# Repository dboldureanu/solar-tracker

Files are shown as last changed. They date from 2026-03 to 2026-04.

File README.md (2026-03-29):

# Solar Tracker Project

A custom-built solar tracking system powered by an ESP32, designed to control multiple linear actuators with a user-friendly interface and safe power management.

---

## Overview

This project controls **three linear actuators** used to adjust the position of a solar panel system.
It features a **rotary encoder + LCD interface**, allowing manual control, monitoring, and future automation.

The system is designed with:
- Safe **power sequencing** (buck converter + relays)
- Modular **hardware architecture**
- Expandable **firmware (FSM-based design)**

---

## Features

- Real-time clock (RTC) display
- Rotary encoder navigation (pages + control mode)
- Safe actuator control via relay sequencing
- Buck converter pre-charge + main relay logic
- Microwave-style timing control (+30s / -30s)
- LCD interface (20x4 I2C)
- Potentiometer feedback for calibration
- Expandable for sensors (INA226 monitoring)

---

## System Architecture

The system is divided into several subsystems:

- **Control Unit** -> ESP32 (main logic)
- **User Interface** -> LCD + rotary encoder
- **Power System** -> 48V -> buck converter -> relays
- **Actuation** -> 3x linear actuators
- **Sensors** -> RTC + optional current/voltage monitors

---

## Documentation

Full project documentation is in the `docs/` folder:

| File | Topic |
|---|---|
| [01-overview.md](docs/01-overview.md) | System architecture and purpose |
| [02-hardware.md](docs/02-hardware.md) | Hardware components |
| [03-wiring.md](docs/03-wiring.md) | Wiring and pin mapping (single source of truth) |
| [04-power-architecture.md](docs/04-power-architecture.md) | Power design and sequencing |
| [05-firmware.md](docs/05-firmware.md) | Firmware architecture and FSM |
| [06-ui-behavior.md](docs/06-ui-behavior.md) | UI behavior and interaction |
| [pinout.md](docs/pinout.md) | Quick-reference pin table |

---

## Getting Started

### Requirements

- ESP32 DevKit board (ESP32-WROOM-32 / 32D, 38-pin)
- Arduino IDE
- USB cable (Type-C or Micro-B depending on board)

### Arduino IDE Setup

#### 1. Install ESP32 board support

1. **File** -> **Preferences**
2. In **"Additional Board Manager URLs"**, paste:
   ```
   https://raw.githubusercontent.com/espressif/arduino-esp32/gh-pages/package_esp32_index.json
   ```
   (If you already have other URLs, separate them with a comma)
3. Click **OK**
4. **Tools** -> **Board** -> **Boards Manager**
5. Search for **"esp32"**, install **"ESP32 by Espressif Systems"**

#### 2. Install required libraries

- **Tools** -> **Manage Libraries**, then search and install:
  - **hd44780** by Bill Perry (LCD driver)
- `Wire` is built-in, no installation needed

#### 3. Board settings

- **Tools** -> **Board** -> select **"ESP32 Dev Module"**
- **Tools** -> **Port** -> select the COM port your ESP32 is connected to
- All other settings can stay at defaults

### Building and uploading

1. Open `SolarTracker/SolarTracker.ino` in Arduino IDE
2. Click **Verify** (checkmark) to compile without uploading
3. Connect ESP32 via USB
4. Click **Upload** (arrow) to flash the firmware
5. **Tools** -> **Serial Monitor** at 115200 baud (optional, for debug output)

### Project directories

- `SolarTracker/` — current clean firmware (modular, multi-file)
- `SolarTracker/SolarTrackerCalibrationAndTesting.ino.bak` — original single-file firmware (reference only)

---

## Safety Notes

- Never connect **12V or higher directly to ESP32 VIN**
- Ensure **common ground** between all power sources
- Use proper **relay sequencing** (handled in firmware)
- USB + external power should be **isolated with a diode**

---

## Future Improvements

- Automatic sun tracking algorithm (clock-based scheduling)
- WiFi / remote control
- Data logging
- Closed-loop actuator positioning
- Safety limits and fault detection

---

## License

TBD

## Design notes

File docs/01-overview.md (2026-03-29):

# System Overview

This document describes the overall architecture and purpose of the Solar Tracker system, including its main components and how they interact.

---

## Purpose

The system is designed to control the position of **9 solar panels** (arranged in 3 rows of 3) using **three linear actuators** — one per row — for **azimuth tracking** (east-to-west sun following). Tilt is adjusted manually.

The installation is located in **Chisinau, Moldova** (latitude 47.0°N, longitude 28.8°E).

The primary goals are:
- Reliable actuator control
- Safe power management
- Simple and intuitive user interaction
- Clock-based automatic sun tracking

---

## High-Level Architecture

The system is composed of the following main subsystems:

```
        +---------------------+
        |     User Input      |
        |  (Rotary Encoder)   |
        +----------+----------+
                   |
                   v
        +---------------------+
        |      ESP32 MCU      |
        |   (Control Logic)   |
        +----+----+----+------+
             |    |    |
             |    |    |
 +-----------+    |    +-----------+
 |                |                |
 v                v                v
+---------+ +-----------+ +-------------+
|   LCD   | |    RTC    | |   Sensors   |
|  (I2C)  | |  DS3231   | |   INA226    |
+---------+ +-----------+ +-------------+
                  |
                  v
        +-------------------+
        |   Relay Control   |
        +---------+---------+
                  |
                  v
        +-------------------+
        |  Linear Actuators |
        |   (3x Motors)     |
        +-------------------+

                  ^
                  |
        +-------------------+
        |   Power System    |
        |  (Buck + Relays)  |
        +-------------------+
```

---

## Subsystems Description

### 1. Control Unit (ESP32)

The **ESP32 DevKitC** acts as the central controller:
- Handles user input (encoder)
- Drives relays
- Manages UI (LCD)
- Communicates with RTC and sensors via I2C
- Executes control logic using a **non-blocking FSM**

---

### 2. User Interface

**Components:**
- Rotary encoder (with push button)
- I2C LCD display (20x4 characters)

**Responsibilities:**
- Page navigation
- Enter/exit control mode
- Display system status (time, actuator info, timers)
- Provide feedback during actuator movement

---

### 3. Actuation System

- **9 solar panels** in 3 rows of 3 (each panel ~60 x 120 cm)
- 3 independent **linear actuators** (one per row, azimuth only)
- Each actuator: 450 mm stroke, 12V, 900N thrust, ~5 mm/s speed (~90s full travel)
- Each actuator controlled by **2 relays** (direction control)
- Only one direction active at a time
- Built-in 10 kOhm potentiometer for position feedback

**Behavior:**
- Controlled in timed pulses
- Direction selected via encoder rotation
- Duration adjustable dynamically (+/-30s steps)

**Tracking strategy:**
- Primary: clock-based positioning (calculate sun azimuth from time + Chisinau coordinates)
- Secondary: potentiometer feedback for closed-loop position verification
- Fallback: timed movement (actuator speed is ~5 mm/s, determined experimentally)

---

### 4. Power System

The actuators are powered through a controlled sequence:

```
48V Source
    |
    v
Buck Converter (48V -> 12V)
    |
    v
Pre-charge Relay
    |
    v
Main Relay
    |
    v
Actuator Relays
    |
    v
Linear Actuators
```

**Key concept:**
- The buck converter is **not always on**
- It is enabled only when movement is required
- Controlled via **two relays (PRE + MAIN)**

---

### 5. Sensors

**RTC (DS3231)**
- Keeps track of date and time
- Battery-backed
- Used for display and future automation

**INA226 (optional / planned)**
- Measures voltage, current, power
- Enables monitoring and diagnostics

**Potentiometers**
- Provide analog feedback
- Used for actuator calibration

---

## Software Architecture

The firmware is designed around:

### 1. State-based control (FSM)
Handles:
- Power sequencing
- Actuator movement lifecycle
- Safe transitions

### 2. Non-blocking execution
- Uses `millis()` instead of delays
- Allows UI + control to run simultaneously

### 3. Page-based UI
- 4 pages: Clock, Actuator A, Actuator B, Actuator C

---

## Typical Operation Flow

1. System boots -> displays clock page
2. User rotates encoder -> switches pages
3. User selects actuator page
4. User presses button -> enters control mode
5. User rotates encoder -> actuator starts moving
6. System:
   - Powers buck (PRE -> MAIN)
   - Activates actuator relay
   - Runs for defined duration
7. User can:
   - Increase time (+30s)
   - Decrease time (-30s)
   - Stop movement early
8. System safely powers down:
   - Actuator OFF -> MAIN OFF -> PRE OFF

---

## Design Principles

- **Safety first** -> controlled power sequencing
- **Non-blocking logic** -> responsive UI
- **Modularity** -> easy to extend
- **Clarity** -> explicit states and transitions

---

## Notes

- Only one actuator is controlled at a time
- Relays are **active LOW**
- USB + external power coexist with proper isolation
- Manual control is working; clock-based automatic tracking is the next step

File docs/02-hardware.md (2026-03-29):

# Hardware Components

This document describes all physical components used in the Solar Tracker system, including control boards, actuators, power elements, and interface devices.

---

## Control Unit

### ESP32 DevKitC v4

- Main microcontroller of the system
- Dual-core processor with WiFi/Bluetooth capability
- Operates at 3.3V logic level
- Provides:
  - GPIO control for relays
  - ADC inputs for potentiometers
  - I2C communication (RTC, LCD, sensors)
  - Encoder input handling

---

## User Interface

### I2C LCD Display

- **Model:** LCD2004, 20x4 character LCD, [AliExpress listing](https://aliexpress.ru/item/1005006831710761.html)
- Interface: I2C via PCF8574 backpack (auto-detected by `hd44780_I2Cexp` driver)
- I2C address: auto-detected (typically 0x27 or 0x3F)

| Parameter | Value |
|---|---|
| Resolution | 20x4 characters |
| Controller chip | SPLC780C / HD44780 compatible |
| Operating voltage | 3.3V |
| Power consumption | 40 mA |
| Display type | STN/FSTN |
| Backlight | Blue (white on blue) or Yellow-green |
| Display area | 70.1 x 20.76 mm |
| Module dimensions | 98 x 60 x 14 mm |
| Character size | 2.94 x 4.74 mm |
| Operating temperature| -20 to +70 C |

- Used for:
  - Displaying system status
  - Navigation feedback
  - Actuator control information

### Rotary Encoder (with push button)

- Model: **EC11** (Stlxy), [AliExpress listing](https://aliexpress.ru/item/10000056483250.html)
- Type: Incremental rotary encoder (A/B quadrature signals)
- 20 detent positions, 360-degree rotation
- Integrated momentary push button
- 5-pin (A, B, Button, GND, GND)
- Used for:
  - Page navigation
  - Entering/exiting control mode
  - Adjusting actuator movement duration

---

## Actuation System

### Linear Actuators (x3)

- Used to physically move/adjust the solar panel
- Each actuator supports:
  - Bidirectional movement
  - Controlled via polarity switching (relays)
  - Built-in potentiometer for position feedback
  - Built-in end-stop limit switches (both ends)

**Model:** XINHUANGDUO BHTGA-DW ([AliExpress listing](https://aliexpress.ru/item/1021789697.html))

| Parameter | Value |
|---|---|
| Stroke | 450 mm |
| Operating voltage | 12V DC |
| Max current | 2.5 A |
| Max push force (thrust) | 900 N |
| Max pull force | 750 N |
| Static load (forced) | 950 N |
| Max load | 1500 N |
| Self-locking force | 2300 N |
| Feedback potentiometer | Linear (1k / 5k / 10k options) |
| End-stop limit switches | Built-in (both ends) |
| Speed (approx) | ~5 mm/s (~90s full stroke) |
| Power | 20W |
| Motor type | Brushed, permanent magnet |
| Protection rating | IP65 (IEC-60529) |
| Operating temperature | -26 to +65 C |
| Operating humidity | 5-95% (non-condensing) |
| Duty cycle | 20% |
| Lifespan | 50,000 full cycles |
| Construction | Aluminum alloy tube/rods, zinc alloy housing, powder metal gears |

### Relay Modules

- Total relays used: **8** (6-channel module for actuators + 2-channel module for buck control)
- Brand: **Liludin**, optocoupler-isolated, low-level trigger
- [AliExpress listing](https://aliexpress.ru/item/1005004651717236.html)

| Parameter | Value |
|---|---|
| Trigger level | Active LOW (0-2V for 5V version) |
| Trigger current | 2 mA |
| Quiescent current | 4 mA (5V version) |
| Operating current | 65 mA (5V version) |
| Contact rating | 250V 10A AC / 30V 10A DC |
| Isolation | Optocoupler |
| Operating temperature| -45 to +85 C |
| Mounting | 3.1 mm bolt holes |

**Allocation:**

| Function | GPIO | Description |
|---|---|---|
| Actuator A | 13, 14 | Direction control |
| Actuator B | 16, 17 | Direction control |
| Actuator C | 18, 19 | Direction control |
| Buck Main | 23 | Enables main power  |
| Buck Pre-charge  | 25 | Soft-start |

**Notes:**
- Each actuator uses **2 relays** (forward/reverse)
- Only one direction must be active at a time
- All relays default to **OFF (HIGH)**
- Each relay has NO (normally open), NC (normally closed), and COM terminals

---

## Power System

### Primary Source

- **48V battery bank**: 4x 12V 200Ah lead-acid gel batteries in series
- Nominal voltage: 48V (range ~42-56V depending on charge state)

### ESP32 Power: HV DC-DC Buck (48V -> 5V)

Powers the ESP32 and logic-level components (always on).

- **Chip:** XL7035 (replaces XL7015 / LM2596HV)
- **Brand:** eletechsup, [AliExpress listing](https://aliexpress.ru/item/32824319280.html)

| Parameter | Value |
|---|---|
| Input voltage | 10-80V DC |
| Output voltage | 5V DC (fixed) |
| Max output current | 1A |
| Switching frequency | 150 kHz |
| Max efficiency | 85% |
| Quiescent current | ~2.5 mA |
| Operating temperature | -40 to +85 C |
| Dimensions | 59 x 30 x 16 mm |

**Protections:** reverse polarity input, overvoltage (TVS), overcurrent, thermal shutdown, short circuit.

### Actuator Power: Buck Converter (48V -> 12V)

Powers the linear actuators. **Not always on** — enabled only when movement is required, controlled via two relays with safe power sequencing.

- **Type:** 200W synchronous buck module (non-isolated), [AliExpress listing](https://aliexpress.ru/item/1005010087482983.html)
- Output voltage adjustable via potentiometer (default 12V)

| Parameter | Value |
|---|---|
| Input voltage | 8-55V DC (abs max 60V) |
| Output voltage | 1-36V DC adjustable (set to 12V)|
| Output current | 10A continuous, 15A peak |
| Output power | 100W natural cooling, 200W with enhanced cooling |
| Switching frequency | 180 kHz |
| Max efficiency | 94% |
| Operating temperature | -10 to +85 C |
| Dimensions | 70 x 38 x 31 mm (aluminum case) |
| Connection | Screw terminals (no soldering) |

**Protections:** overcurrent (>15A), reverse polarity input.

### Buck Control Relays

Two relays are used to safely control the actuator buck converter:

1. **Pre-charge relay** (GPIO 25)
   - Allows gradual energizing
   - Reduces inrush current

2. **Main relay** (GPIO 23)
   - Supplies full power after stabilization

### USB Power (Development)

- ESP32 can also be powered via USB
- Used for programming and serial debugging

**Isolation:**
- USB 5V line is **diode-isolated** (1N4007)
- Prevents backfeeding into the laptop

---

## Sensors

### DS3231 RTC Module

- **Chip:** DS3231SN with AT24C32 EEPROM (32Kbit)
- **Brand:** Liludin, [AliExpress listing](https://aliexpress.ru/item/1005001875764383.html)
- Module: DS3231 mini module (3.3V/5V compatible)
- Battery: LIR2032 rechargeable (keeps clock running when main power is off)
- Communicates via I2C (RTC address 0x68, EEPROM address 0x57 — adjustable via A0/A1/A2)
- I2C max speed: 400 kHz at 5V

| Parameter | Value |
|---|---|
| Operating voltage | 3.3-5.5V |
| Clock accuracy | +/-2 ppm (0-40 C range, ~1 min/year) |
| Temperature sensor | Built-in, +/-3 C accuracy |
| EEPROM | AT24C32, 32Kbit |
| Alarms | 2 configurable |
| Square wave output | Programmable |
| Calendar valid until | Year 2100 (with leap year compensation) |
| Dimensions | 38 x 22 x 14 mm |

### INA226 Current/Voltage Sensors (optional)

- **Chip:** INA226, **Brand:** diymore, [AliExpress listing](https://aliexpress.ru/item/1005006460678073.html)
- I2C current/voltage/power monitor with shunt resistor

| Parameter | Value |
|---|---|
| Bus voltage range | 0-36V DC |
| Current range | -20A to +20A (bidirectional) |
| Supply voltage | 2.7-5.5V |
| Resolution | 16-bit (1.25 mA current, 1.25 mV voltage) |
| Accuracy | 1% |
| Power consumption | ~330 uA (typ), <1 mA |
| Interface | I2C (up to 16 addresses via A0/A1 solder jumpers) |
| Alert output | Programmable alarm pin |
| Operating temperature  | -40 to +125 C |
| Dimensions | 20 x 27 mm |

- Used for monitoring actuator current draw and system diagnostics
- Connected to ESP32 INA ALERT pin (GPIO 27) for alarm notifications

### Potentiometers (x3)

- **Built into the linear actuators** (10 kOhm linear)
- Connected to ESP32 ADC1 pins (GPIO 34, 35, 36)
- Provide analog position feedback for each actuator
- Used for calibration and position estimation

**Signal conditioning circuit (per channel):**

```
Actuator pot (0-5V) ──[ 1kΩ series ]──┬── ESP32 ADC pin (0-3.3V)
                                       |
                                  [ 100nF ]
                                       |
                                      GND
                                       |
                                  [ 10kΩ pull-down ]
                                       |
                                      GND
```

- **1 kOhm series resistor**: limits current into ADC, protects ESP32
- **100 nF capacitor to GND**: low-pass RC filter (RC = ~100 us), smooths voltage spikes and mechanical noise
- **10 kOhm pull-down**: prevents floating voltage at mid-stroke
- Note: a voltage divider may be needed to scale 5V pot output to 3.3V ADC range

---

## Passive Components

### Diodes

- Used for power isolation
- Current: **1N4007**
  - Prevents reverse current into USB
  - Installed inline on USB 5V (VCC)

> For better efficiency, Schottky diodes (e.g., 1N5819) are recommended in future revisions.

---

## Connectivity

### I2C Bus

Shared by: LCD, RTC, INA226 sensors

### GPIO

Used for: relay control, encoder signals, button input

---

## Important Notes

- All grounds (**GND**) must be common across: ESP32, power system, sensors
- Relays are **active LOW**
- External power must be properly regulated before reaching the ESP32

---

## Future Hardware Improvements

- Replace mechanical relays with MOSFET-based drivers
- Add end-stop sensors for actuators
- Add hardware protection (fuses, TVS diodes)
- Improve power isolation (ideal diode or power mux)

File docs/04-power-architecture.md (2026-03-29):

# Power Architecture

This document describes how power is generated, controlled, and safely delivered to the system components.

The design ensures:
- Safe startup and shutdown
- Controlled high-current switching
- Protection of both hardware and USB-connected devices

---

## Overview

The system uses a **48V battery bank** (4x 12V 200Ah lead-acid gel in series) which is stepped down by two separate converters.

```
48V Battery Bank (4x 12V 200Ah gel, series)
    |
    +---> HV Buck XL7035 (48V -> 5V, always on)
    |         |
    |         v
    |     ESP32 + sensors + LCD (logic power)
    |
    +---> Buck Converter (48V -> 12V, relay-controlled)
              |
              v
          Pre-charge Relay (GPIO 25)
              |
              v
          Main Relay (GPIO 23)
              |
              v
          Actuator Relays (GPIO 13-19)
              |
              v
          Linear Actuators
```

---

## Power Domains

### 1. High Power Domain

- **48V battery bank** (4x 12V 200Ah lead-acid gel, series)
- Nominal 48V (range ~42-56V depending on charge state)
- Feeds both buck converters

### 2. Intermediate Power (12V)

- Output of the relay-controlled buck converter
- Supplies linear actuators only
- Not always on — enabled only during movement

### 3. Logic Power (5V / 3.3V)

- **HV DC-DC buck module** (XL7035, 10-80V -> 5V, 1A max)
- Always on when battery is connected
- Powers ESP32, sensors, LCD
- ESP32 internal regulator provides 3.3V from 5V

Additional source:
- USB (development only, diode-isolated)

---

## Buck Converter Control

The buck converter is **not permanently active**.
It is enabled only when actuator movement is required.

### Control Relays

| Relay | Function |
|---|---|
| Pre-charge | Soft-start / limits inrush |
| Main | Full power enable |

---

## Power Sequencing (Critical)

To prevent electrical stress and ensure safe operation, the following sequence is enforced:

### Startup Sequence

1. **Pre-charge relay ON**
   - Allows gradual capacitor charging
2. Wait (~400 ms)
3. **Main relay ON**
   - Full power applied
4. Wait (~150 ms)
5. **Actuator relay ON**
   - Movement begins

### Shutdown Sequence

1. **Actuator relay OFF**
2. Wait (~100 ms)
3. **Main relay OFF**
4. Wait (~150 ms)
5. **Pre-charge relay OFF**

### Why this matters

- Prevents **inrush current spikes**
- Protects relays and buck converter
- Avoids voltage dips affecting ESP32
- Ensures longer hardware lifespan

---

## USB + External Power Coexistence

The ESP32 may be powered simultaneously by:
- USB (from laptop)
- External regulated 5V

### Problem

Without protection:
- External power can **backfeed into USB**
- Risk of damaging the laptop

### Solution: Diode Isolation

A diode is added in the USB 5V line:

```
Laptop USB 5V ──|>|──> ESP32 5V
```

- Allows power from USB -> ESP32
- Blocks power from ESP32 -> USB

### Implementation

- Diode used: **1N4007**
- Orientation:
  - Anode -> USB side
  - Cathode (stripe) -> ESP32 side

### Voltage Drop

- Typical drop: ~0.7V
- Result: ESP32 receives ~4.3V from USB
- Still within acceptable operating range

### Future Improvement

- Replace with **Schottky diode** (e.g., 1N5819)
  - Lower drop (~0.2-0.3V)
  - More efficient

---

## Grounding

All system parts must share a **common ground**:
- ESP32
- Buck converter
- Relay modules
- Sensors
- External power source

> This is essential for stable operation and correct signal reference.

---

## Safety Considerations

### DO

- Use proper voltage regulation (48V -> 12V -> 5V)
- Verify polarity before powering
- Ensure solid connections for high-current paths

### DO NOT

- Connect 12V directly to ESP32 VIN/5V
- Operate relays without proper sequencing
- Use floating grounds
- Connect USB to a system with unknown ground potential

---

## Risk Areas

- High current during actuator startup
- Relay contact wear over time
- Voltage spikes from inductive loads (actuator motors)

---

## Recommended Protections (Future)

- Flyback diodes on relay coils
- TVS diodes for surge protection
- Fuses on power lines
- Current limiting on actuator lines

---

## Notes

- Power system is designed for **intermittent operation**, not continuous load
- Buck converter should not remain powered unnecessarily
- Firmware enforces all sequencing logic

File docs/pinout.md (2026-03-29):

# ESP32 Pin Mapping (Quick Reference)

## GPIO Assignments

| GPIO | Function  | Connected To | Notes |
|---|---|---|---|
| 13 | Relay | Actuator A - Direction 1  | Active LOW |
| 14 | Relay | Actuator A - Direction 2  | Active LOW |
| 16 | Relay | Actuator B - Direction 1  | Active LOW |
| 17 | Relay | Actuator B - Direction 2  | Active LOW |
| 18 | Relay | Actuator C - Direction 1  | Active LOW |
| 19 | Relay | Actuator C - Direction 2  | Active LOW |
| 23 | Relay | Buck MAIN relay | Active LOW |
| 25 | Relay | Buck PRE-charge relay | Active LOW |
| 32 | Input | Encoder A | INPUT_PULLUP |
| 33 | Input | Encoder B | INPUT_PULLUP |
| 26 | Input | Encoder Button | INPUT_PULLUP |
| 34 | ADC | Potentiometer A | Input-only |
| 35 | ADC | Potentiometer B | Input-only |
| 36 | ADC | Potentiometer C | Input-only |
| 27 | Input | INA ALERT | INPUT_PULLUP |
| 21 | I2C SDA | LCD, RTC, INA226 | Shared bus |
| 22 | I2C SCL | LCD, RTC, INA226 | Shared bus |

---

## Power Pins

| Pin | Function | Notes |
|---|---|---|
| VIN / 5V | Power input | From USB or external 5V |
| 3V3 | Regulated output | Internal ESP32 regulator |
| GND | Ground | Must be common everywhere |

---

## Special Notes

### Input-only pins
- GPIO **34, 35, 36** cannot be used as outputs
- Used for ADC (potentiometer readings)

### Active LOW relays

All relay pins:

| Signal | Meaning |
|---|---|
| LOW | Relay ON |
| HIGH | Relay OFF |

### I2C Bus

- SDA -> GPIO 21
- SCL -> GPIO 22

Devices on the bus:
- LCD display
- RTC (DS3231)
- INA226 sensors

### Avoided Pins

Pins intentionally not used:
- GPIO 0, 2, 15 -> boot-strapping pins
- GPIO 6-11 -> used by internal flash memory

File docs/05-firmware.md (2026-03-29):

# Firmware Architecture

This document describes the structure, logic, and design principles of the firmware running on the ESP32.

The firmware is responsible for:
- User interaction (encoder + LCD)
- Actuator control
- Power sequencing
- Timing and state management

---

## High-Level Structure

The firmware follows a **non-blocking, state-driven architecture**:

```
loop()
├── pollEncoder()
├── tickMoveFSM()
├── drawUI()
└── periodicTasks()
```

---

## Core Concepts

### 1. Non-blocking Execution

- Uses `millis()` instead of `delay()`
- Allows:
  - Responsive UI
  - Concurrent operations
  - Smooth timing control

### 2. Finite State Machine (FSM)

The actuator movement and power control are implemented using a **state machine**.

---

## Move FSM

### States

```
Idle
 ├─ PreOn
 ├─ MainOn
 ├─ ActOn
 ├─ ActOffPause
 ├─ MainOff
 └─ PreOff
```

### State Descriptions

| State | Description |
|---|---|
| Idle | No movement |
| PreOn | Pre-charge relay ON |
| MainOn | Main relay ON |
| ActOn | Actuator running |
| ActOffPause | Short delay after stop |
| MainOff | Main relay OFF |
| PreOff | Pre-charge OFF |

### Transition Flow

```
Idle → PreOn → MainOn → ActOn → ActOffPause → MainOff → PreOff → Idle
```

### Timing Constants

| Constant | Value | Purpose |
|---|---|---|
| `PRECHARGE_MS` | 400 ms | Soft-start |
| `MAIN_STAB_MS` | 150 ms | Stabilization |
| `PULSE_MS` | 30000 ms | Base movement time |
| `POST_ACT_PAUSE_MS`| 100 ms  | Safe stop |
| `BUCK_SPINDOWN_MS` | 150 ms | Power-down |

---

## Input Handling

### Rotary Encoder

- Quadrature decoding (A/B signals)
- Accumulates steps
- Converts into actions:
  - Page navigation
  - Actuator control

### Sensitivity Control

| Mode | Constant | Value | Purpose |
|---|---|---|---|
| Navigation | `NAV_TICKS_PER_ACTION` | 4 | Prevent oversensitivity |
| Control | `CTRL_TICKS_PER_PULSE` | 2 | Avoid accidental triggers |

### Button Handling

- Detects rising edge (press)
- Used for:
  - Entering control mode
  - Exiting control mode

---

## UI System

### Page-Based Design

| Page | Description |
|---|---|
| 0 | Clock |
| 1 | Actuator A  |
| 2 | Actuator B  |
| 3 | Actuator C  |

### Rendering Strategy

- Only redraw when needed
- Clock updates every second
- Actuator pages update dynamically

---

## Control Mode Logic

### Entry

- Press encoder on actuator page

### Behavior

- Encoder rotation triggers movement
- Direction:
  - CW -> one direction (dir2)
  - CCW -> opposite direction (dir1)

---

## Microwave-Style Timing

### Key Idea

While an actuator is running, encoder rotation adjusts the remaining time:
- **CW** (clockwise) always **adds +30 seconds** (regardless of which direction started the move)
- **CCW** (counter-clockwise) always **subtracts -30 seconds**

### Constants

| Constant | Value | Purpose |
|---|---|---|
| `PULSE_MS` | 30000 ms | Initial movement time  |
| `MOVE_INCREMENT_MS`| 30000 ms | Time added/removed |
| `MAX_MOVE_MS` | 60000 ms | Maximum run time cap |

### Behavior

1. First rotation -> starts movement (30s). CW starts dir2, CCW starts dir1.
2. While running, time adjustment is always:
   - CW: extend time (+30s, capped at 60s total from start)
   - CCW: reduce time (-30s)
3. If time reaches 0 -> actuator stops immediately, FSM begins shutdown
4. Note: CW/CCW for time adjustment is independent of which direction started the move

### Runtime Adjustment

While actuator is running:
- Encoder input modifies `move.nextAt`
- Remaining time recalculated dynamically
- Display updates continuously

---

## Early Stop Logic

If user reduces time to 0:
1. Actuator stops immediately
2. FSM continues shutdown sequence safely (ActOffPause -> MainOff -> PreOff -> Idle)

---

## Relay Control Logic

- All relays are **active LOW**
- Default state = OFF (HIGH)

### Actuator Control

| dir1 | dir2 | Result |
|---|---|---|
| LOW  | HIGH | Direction 1 |
| HIGH | LOW  | Direction 2 |
| HIGH | HIGH | Stop |

> Both LOW simultaneously must never occur (short circuit risk).

---

## ADC Handling

- Uses ESP32 ADC1 (pins 34, 35, 36)
- Reads potentiometers for actuator feedback
- 12-bit resolution (0-4095)
- 11 dB attenuation (~0-3.3V range)
- Applies multi-sample averaging (12 samples) for stability

---

## Periodic Tasks

| Task | Interval | Condition |
|---|---|---|
| Clock refresh | 1 second | On clock page |
| Potentiometer update  | ~200 ms  | On actuator page, not in control mode |

---

## Design Principles

- **Responsiveness** -> no blocking delays
- **Safety** -> enforced power sequencing
- **Predictability** -> explicit FSM states
- **Extensibility** -> easy to add features

---

## Future Improvements

- Event-driven architecture
- Task scheduling (RTOS)
- Persistent settings (EEPROM / NVS)
- Automated sun-tracking control algorithm

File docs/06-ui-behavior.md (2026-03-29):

# UI Behavior

This document describes how the user interacts with the system via the **rotary encoder and LCD**, including navigation, control modes, and on-screen feedback.

---

## Navigation Model

The UI is based on a **page system**, controlled by the rotary encoder.

### Pages

| Page Index | Name | Description |
|---|---|---|
| 0 | Clock | Displays date/time |
| 1 | Actuator A | Control page |
| 2 | Actuator B | Control page |
| 3 | Actuator C | Control page |

---

## Page Navigation

### Rotation (Normal Mode)

- Rotate encoder:
  - Clockwise -> next page
  - Counter-clockwise -> previous page

### Sensitivity

- Navigation requires multiple encoder ticks
- Controlled by `NAV_TICKS_PER_ACTION` (currently 4)
- Prevents accidental page switching

---

## Button Behavior

| Page | Button Action |
|---|---|
| Clock | No action |
| Actuator pages | Enter / Exit control mode |

---

## Control Mode

### Entering Control Mode

1. Navigate to an actuator page
2. Press encoder button

-> System enters **control mode**

### Exiting Control Mode

- Press encoder button again
- Returns to normal navigation mode
- If a move is in progress, the FSM continues its shutdown safely

---

## Control Mode Behavior

While in control mode:

### Encoder Rotation

| Direction | Action |
|---|---|
| Clockwise | Move actuator (dir2) |
| Counter-clockwise | Move actuator (dir1) |

---

## Microwave-Style Timing

The system uses a **cumulative timing model**, similar to a microwave.

### Behavior

- First rotation:
  - Starts actuator movement
  - Sets initial time = **30 seconds**
- Additional rotations (while running):
  - CW always adds **+30 seconds** (capped at 60s total from start)
  - CCW always subtracts **-30 seconds**
  - Note: this is independent of which direction started the move

### Examples

| Action | Result |
|---|---|
| Rotate CW once | Start 30s |
| Rotate CW again  | 60s total (max cap) |
| Rotate CCW once  | Back to 30s |
| Reduce to 0 | Movement stops |

---

## Stop Behavior

- If remaining time reaches **0**:
  - Actuator stops immediately
  - Power-down sequence begins (ActOffPause -> MainOff -> PreOff -> Idle)

---

## Display Layouts

### 1. Clock Page

```
Date & Time
YYYY-MM-DD
HH:MM:SS
Rotate: pages | Btn: -
```

- Updates every second
- Button has no effect

### 2. Actuator Page (Normal Mode)

```
Actuator A
POT: 2048  1.65V
Rotate: next/prev
Btn: Control mode
```

- Shows actuator name
- Potentiometer value (raw ADC + voltage)

### 3. Actuator Page (Control Mode - Idle)

```
Actuator A
POT: 2048  1.65V
CONTROL: rotate =>
Dir: CCW<-  ->CW
```

- Waiting for user input
- No movement active

### 4. Actuator Page (Running)

```
Actuator A
POT: 2048  1.65V
CONTROL: rotate =>
Remain: 00:25
```

- Displays remaining time as MM:SS
- Updates continuously

### 5. Time Adjustment Feedback

When adjusting time while running:

- Adding time:
  ```
  Remain: 01:00 (+30s)
  ```
- Reducing time:
  ```
  Remain: 00:30 (-30s)
  ```

---

## Real-Time Updates

| Element | Update Rate |
|---|---|
| Clock | 1 second |
| Potentiometer | ~200 ms |
| Remaining time | Continuous  |

---

## Interaction Summary

### Normal Mode

- Rotate -> change page
- Button -> enter control (only on actuator pages)

### Control Mode

- Rotate -> control actuator (direction + time)
- Button -> exit control mode

---

## Important Behavior Rules

- Only one actuator can be controlled at a time
- Control mode disables page navigation
- Movement continues even if UI updates
- FSM handles safe power transitions independently

---

## UX Notes

- Encoder sensitivity intentionally reduced to avoid accidental movements
- Visual feedback always matches system state

---

## Possible UI Improvements

- Add icons or arrows for direction
- Display actuator position as percentage
- Add warnings (overcurrent, limits)
- Add confirmation before movement
- Add menu/settings page

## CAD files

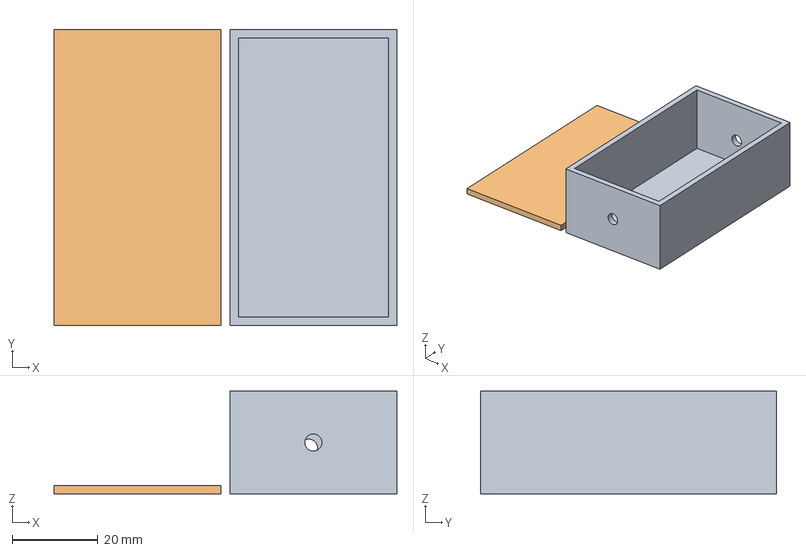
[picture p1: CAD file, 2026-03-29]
3d/Capac48to5V.3mf
80.0 x 69.0 x 24.0 mm
Cutie48to5V.stl
Capac48to5V.stl

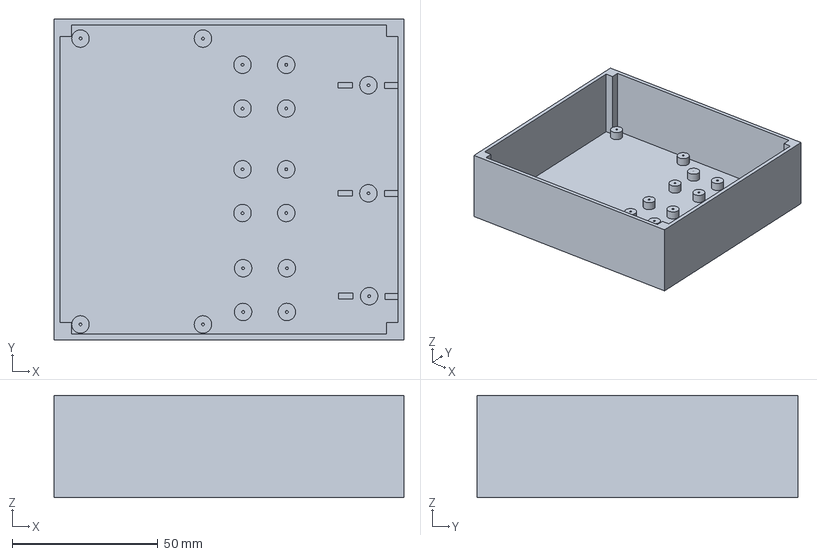
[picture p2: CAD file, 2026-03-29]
3d/RelaysCaseBase.3mf
120.0 x 110.0 x 35.0 mm

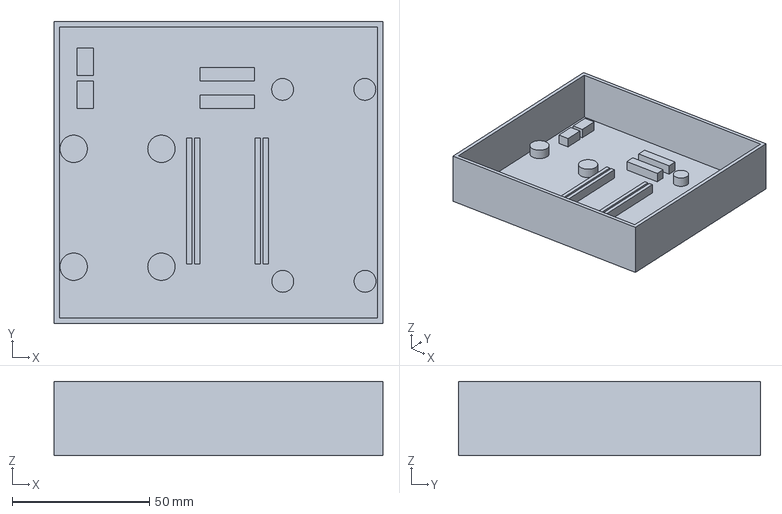
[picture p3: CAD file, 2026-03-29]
3d/Esp32Base.3mf
120.0 x 110.0 x 27.0 mm

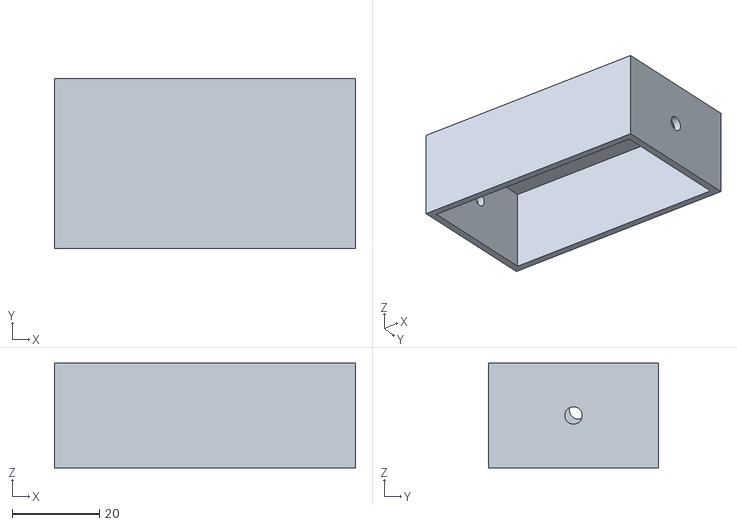
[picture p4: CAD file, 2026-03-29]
3d/Cutie48to5V.stl
69.0 x 39.0 x 24.0

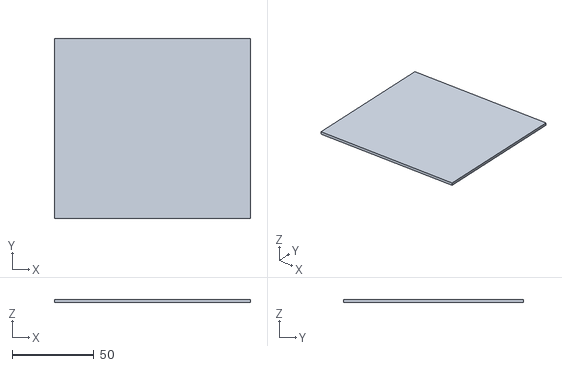
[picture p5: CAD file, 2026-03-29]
3d/CapacSolarTracker.stl
120.0 x 110.0 x 2.00

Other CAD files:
3d/Capac48to5V.stl
3d/Esp32Base.stl
3d/RelaysCaseBase.stl

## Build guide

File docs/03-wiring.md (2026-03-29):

# Wiring & Pin Mapping

This document defines all electrical connections between the ESP32 and the system components.
It is the **single source of truth** for pin assignments and wiring.

---

## ESP32 Pin Mapping

### I2C Bus

| Function | GPIO | Notes |
|---|---|---|
| SDA | 21 | Shared bus |
| SCL | 22 | Shared bus |

Connected devices:
- LCD (I2C)
- RTC (DS3231)
- INA226 sensors

---

### Actuator Relays

Each actuator is controlled by **2 relays** (direction control).

| Actuator | Direction | GPIO |
|---|---|---|
| A | dir1 | 13 |
| A | dir2 | 14 |
| B | dir1 | 16 |
| B | dir2 | 17 |
| C | dir1 | 18 |
| C | dir2 | 19 |

> Only one direction relay must be ON at a time.

---

### Buck Converter Control

| Function | GPIO | Description |
|---|---|---|
| Pre-charge relay | 25 | Enables soft-start |
| Main relay | 23 | Enables full power |

---

### Rotary Encoder

| Signal | GPIO | Notes |
|---|---|---|
| Encoder A | 32 | INPUT_PULLUP |
| Encoder B | 33 | INPUT_PULLUP |
| Button | 26 | INPUT_PULLUP |

---

### Potentiometers (ADC)

| Potentiometer | GPIO | ADC Channel |
|---|---|---|
| Actuator A | 34 | ADC1 |
| Actuator B | 35 | ADC1 |
| Actuator C | 36 | ADC1 |

> These are **input-only pins** (no digital output).

---

### Other Signals

| Function  | GPIO | Notes |
|---|---|---|
| INA ALERT | 27 | INPUT_PULLUP |

---

## Wiring Overview

### I2C Connections

All I2C devices share the same lines:

```
ESP32 GPIO21 (SDA) ─────┬── LCD
                         ├── RTC (DS3231)
                         └── INA226 modules

ESP32 GPIO22 (SCL) ─────┬── LCD
                         ├── RTC
                         └── INA226 modules
```

> Pull-up resistors are typically included on modules.

---

### Relay Wiring (Logic Side)

- Relay modules connect directly to ESP32 GPIOs
- Logic is **active LOW**:

| Signal | State | Meaning |
|---|---|---|
| LOW | ON | Relay activated |
| HIGH | OFF | Relay inactive  |

---

### Actuator Control Logic

Each actuator uses two relays:

```
dir1 = LOW,  dir2 = HIGH  ->  move one direction
dir1 = HIGH, dir2 = LOW   ->  move opposite direction
dir1 = HIGH, dir2 = HIGH  ->  STOP
```

> Never set both LOW simultaneously (short circuit risk).

---

### Buck Relay Wiring

```
ESP32 GPIO25  ->  Pre-charge relay
ESP32 GPIO23  ->  Main relay
```

Sequence:
1. PRE ON
2. MAIN ON
3. Actuator ON
4. Actuator OFF
5. MAIN OFF
6. PRE OFF

---

## Power Connections

### ESP32 Power

- Powered via:
  - USB (development)
  - OR external 5V (via VIN/5V pin)

### External Power System

```
48V Source
    |
    v
Buck Converter (48V -> 12V)
    |
    v
Relays (PRE + MAIN)
    |
    v
Actuators
```

### USB Power Isolation

USB 5V line modified with diode:

```
USB 5V ──|>|──> ESP32 5V
```

Prevents backfeeding into laptop.

---

## Critical Rules

### 1. Common Ground

All components MUST share GND:
- ESP32
- Buck converter
- Relays
- Sensors

### 2. Voltage Limits

- ESP32 GPIO: **3.3V only**
- VIN/5V pin: **5V only**
- NEVER connect 12V directly to ESP32

### 3. Relay Safety

- Default state must be OFF (HIGH)
- Avoid switching directions instantly
- Ensure proper sequencing

### 4. Encoder Stability

- Use INPUT_PULLUP
- Keep wires short
- Avoid noise near relay lines

---

## Debug Tips

- If LCD not detected -> check I2C address (use I2C scanner sketch)
- If relays inverted -> logic is active LOW, check wiring
- If encoder unstable -> check grounding and debounce
- If ADC noisy -> average readings in software (firmware uses 12-sample average)

---

## Notes

- Pin assignments are chosen to:
  - Avoid boot-strapping pins (GPIO 0, 2, 15)
  - Avoid flash memory pins (GPIO 6-11)
  - Use ADC1 channels (safe when WiFi is active)
  - Keep I2C on default pins (21, 22)

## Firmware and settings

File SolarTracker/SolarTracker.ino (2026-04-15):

#include <Wire.h>
#include <hd44780.h>
#include <hd44780ioClass/hd44780_I2Cexp.h>

#include "config.h"
#include "hardware.h"
#include "fsm.h"
#include "autotrack.h"
#include "ui.h"

// Global objects
hd44780_I2Cexp lcd;
Encoder encoder;
MoveFSM fsm;
AutoTrack autotrack;
UI ui;

void setup() {
  Serial.begin(115200);

  // Long settle delay at the very top of setup(). Wide-input switching
  // converters (XL7035 / LM2596HV clones) have slow soft-start and poor
  // transient response at cold boot; giving the 5 V rail a full second
  // to stabilize before we start drawing current avoids brown-out loops
  // and marginal I2C init.
  delay(1000);

  // GPIO inputs first — no current draw, harmless at any rail state.
  encoder.init();
  pinMode(INA_ALERT_PIN, INPUT_PULLUP);

  Wire.begin(I2C_SDA, I2C_SCL);
  // Explicitly pin the I2C clock to 100 kHz. Default varies by ESP32 core
  // version; at 400 kHz the rising edges on a ~20 cm shared bus with only
  // the hobby modules' weak internal pull-ups are marginal, which causes
  // occasional character corruption on the LCD. 100 kHz gives each edge
  // 4x more time to settle.
  Wire.setClock(100000);
  Wire.setTimeOut(50);

  // Let the LCD's internal HD44780 power-on reset finish before we start
  // talking to it (datasheet spec ~40 ms; we give it 200 for margin).
  delay(200);

  // LCD init with one retry — hd44780 cold-boot occasionally fails on the
  // first attempt after a marginal power rail and succeeds the second.
  int lcdStatus = lcd.begin(LCD_COLS, LCD_ROWS);
  if (lcdStatus) {
    Serial.print(F("LCD init failed: ")); Serial.println(-lcdStatus);
    delay(500);
    lcdStatus = lcd.begin(LCD_COLS, LCD_ROWS);
    if (lcdStatus) {
      Serial.print(F("LCD init retry failed: ")); Serial.println(-lcdStatus);
    } else {
      Serial.println(F("LCD init recovered on retry."));
    }
  }
  lcd.backlight();

  // Relay init AFTER LCD, matching the legacy firmware order. Keeping this
  // late means the 8 relay GPIOs stay in high-Z (relay modules pull them
  // high via their onboard resistors) until after we've successfully
  // talked to the LCD — fewer simultaneous current draws on the 5 V rail
  // during the critical I2C init window.
  initRelays();

  initAdc();
  Settings::load();

  if (RTC::isPresent()) {
    // Only seed the RTC if it looks uninitialized (dead coin cell / first boot).
    // Otherwise the set-time menu would be clobbered on every reboot.
    RTC::DateTime dt;
    if (!RTC::read(dt) || dt.year < 2024) {
      RTC::setFromCompileTime();
      Serial.println(F("RTC uninitialized; seeded from compile time."));
    } else {
      Serial.println(F("RTC OK; keeping current time."));
    }
  } else {
    Serial.println(F("RTC not found (skip set)."));
  }

  ui.init(lcd);
  ui.setAutoTrack(&autotrack);
  ui.drawCurrentPage(lcd);
}

void loop() {
  ui.handleInput(encoder, fsm, lcd);
  fsm.tick(lcd);
  autotrack.tick(fsm, ui.isUserBusy(), lcd);
  ui.refresh(fsm, lcd);
}

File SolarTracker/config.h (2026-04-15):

#pragma once

// ===== Relay Pins (active LOW) =====
// Each actuator has two direction relays, named by the tracking direction
// they drive the panels toward: east = morning/low-pot, west = evening/high-pot.
// Actuator C is wired with swapped polarity relative to A/B; the swap is
// expressed here so the rest of the code can stay direction-semantic.
struct ActuatorPins {
  int east;
  int west;
};

constexpr ActuatorPins ACTUATOR_PINS[] = {
  {13, 14},  // Actuator A
  {16, 17},  // Actuator B
  {19, 18},  // Actuator C (swapped in software to match wiring)
};
constexpr int ACTUATOR_COUNT = 3;

// Potentiometer calibration: raw ADC values at physical end stops.
// Measured 2026-04-13 with panels driven manually to each extreme.
struct PotCalibration {
  int east_raw;  // extreme east (morning)
  int west_raw;  // extreme west (evening)
};

constexpr PotCalibration POT_CAL[] = {
  {430, 3140},  // A
  {429, 3200},  // B
  {400, 3190},  // C
};

// ===== Monthly tracking window =====
// For each month: the tracking time window and the pot setpoints at its
// endpoints. Between start and end, the target pot is linearly interpolated.
// Outside the window, auto-tracking is idle.
struct MonthConfig {
  uint8_t  start_h;
  uint8_t  start_m;
  uint16_t start_raw;   // target pot at start-of-window (east-ish)
  uint8_t  end_h;
  uint8_t  end_m;
  uint16_t end_raw;     // target pot at end-of-window (west-ish)
};

constexpr uint8_t MONTH_COUNT = 12;

// Encoder pulse -> raw ADC delta when editing a pot setpoint.
constexpr int POT_EDIT_STEP = 10;

// ===== System (global auto-tracking) config =====
// Stored separately from per-month config in NVS.
struct SystemConfig {
  bool    auto_enabled;   // master on/off for auto-tracking
  uint8_t tick_min;       // evaluation interval, minutes (1..180)
};

// Tick interval bounds.
constexpr uint8_t TICK_MIN_MIN = 1;
constexpr uint8_t TICK_MIN_MAX = 180;

// ===== Auto-tracking tuning =====
// Dead-band around the target pot reading; |target - actual| <= this means
// "aligned, don't move". Units: raw 12-bit ADC counts.
constexpr int AUTO_DEADBAND_RAW = 20;

// Stall detection: if the pot hasn't moved by this many raw counts within
// AUTO_STALL_WINDOW_MS, abort the current actuator's move.
constexpr int           AUTO_STALL_DELTA_RAW = 10;
constexpr unsigned long AUTO_STALL_WINDOW_MS = 5000;

// Max consecutive FSM pulses per actuator per auto-track pass. Each pulse
// is PULSE_MS long (30s), so 3 pulses covers a full stroke (~90s).
constexpr uint8_t AUTO_MAX_PULSES = 3;

// All relay GPIO pins (actuators + buck), for bulk init.
constexpr int RELAY_PINS[] = {13, 14, 16, 17, 18, 19, 23, 25};
constexpr int RELAY_COUNT  = sizeof(RELAY_PINS) / sizeof(RELAY_PINS[0]);

// Buck converter control relays
constexpr int BUCK_MAIN_PIN = 23;
constexpr int BUCK_PRE_PIN  = 25;

// ===== Encoder Pins =====
constexpr int ENC_A   = 32;
constexpr int ENC_B   = 33;
constexpr int ENC_BTN = 26;  // LOW when pressed (INPUT_PULLUP)

// ===== Potentiometer ADC Pins (ESP32 ADC1) =====
constexpr int POT_PINS[] = {34, 35, 36};  // A, B, C

// ===== I2C =====
constexpr int I2C_SDA = 21;
constexpr int I2C_SCL = 22;

// ===== INA226 Alert (optional, not used yet) =====
constexpr int INA_ALERT_PIN = 27;

// ===== LCD =====
constexpr int LCD_COLS = 20;
constexpr int LCD_ROWS = 4;

// ===== Encoder Sensitivity =====
// Navigation mode: ticks required to change page
constexpr int NAV_TICKS_PER_ACTION = 4;
// Control mode: ticks required to trigger actuator
constexpr int CTRL_TICKS_PER_PULSE = 2;

// ===== Actuator Timing =====
// Initial movement duration when first triggered
constexpr unsigned long PULSE_MS = 30000UL;          // 30 seconds
// Time added/removed per encoder twist while running
constexpr unsigned long MOVE_INCREMENT_MS = 30000UL;  // +/- 30 seconds
// Maximum total run time
constexpr unsigned long MAX_MOVE_MS = 60000UL;        // 60 seconds

// ===== Buck Power Sequencing Timing =====
constexpr unsigned long PRECHARGE_MS      = 400;   // PRE relay -> MAIN relay
constexpr unsigned long MAIN_STAB_MS      = 150;   // MAIN relay -> actuator ON
constexpr unsigned long POST_ACT_PAUSE_MS = 100;   // actuator OFF -> MAIN relay OFF
constexpr unsigned long BUCK_SPINDOWN_MS  = 150;   // MAIN OFF -> PRE OFF

// ===== Periodic Update Intervals =====
constexpr unsigned long CLOCK_REFRESH_MS = 1000;   // clock page refresh
constexpr unsigned long POT_REFRESH_MS   = 200;    // potentiometer readout refresh

// ===== ADC =====
// 16 samples * ~1250us per sample ~= 20 ms, which covers one full 50 Hz
// mains cycle. This averages out hum and PWM aliasing that back-to-back
// samples would miss.
constexpr int           ADC_SAMPLES              = 16;
constexpr unsigned long ADC_INTERSAMPLE_US       = 1250;

// Median-of-N reads on top of readAdcAvg, for the few decision points
// where the occasional spike (e.g. relay click) would cause a bad move.
constexpr int ADC_STABLE_SAMPLES = 5;  // must be odd

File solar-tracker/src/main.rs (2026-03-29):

use esp_idf_svc::hal::delay::FreeRtos;
use esp_idf_svc::hal::gpio::PinDriver;
use esp_idf_svc::hal::peripherals::Peripherals;
use log::info;

fn main() {
    // Initialize ESP-IDF system (logger, event loop, etc.)
    esp_idf_svc::sys::link_patches();
    esp_idf_svc::log::EspLogger::initialize_default();

    info!("Solar Tracker - Phase 1: Blink & Serial");
    info!("ESP32 Rust toolchain is working!");

    let peripherals = Peripherals::take().unwrap();

    // Onboard LED is typically on GPIO 2 for ESP32 DevKit boards
    let mut led = PinDriver::output(peripherals.pins.gpio2).unwrap();

    let mut counter: u32 = 0;
    loop {
        led.set_high().unwrap();
        info!("LED ON  (cycle {})", counter);
        FreeRtos::delay_ms(500);

        led.set_low().unwrap();
        info!("LED OFF (cycle {})", counter);
        FreeRtos::delay_ms(500);

        counter += 1;
    }
}

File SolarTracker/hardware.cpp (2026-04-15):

#include "hardware.h"
#include <Preferences.h>

// =====================================================================
// Relay helpers
// =====================================================================

void initRelays() {
  for (int i = 0; i < RELAY_COUNT; i++) {
    pinMode(RELAY_PINS[i], OUTPUT);
    digitalWrite(RELAY_PINS[i], HIGH);  // OFF (active LOW)
  }
}

void allRelaysOff() {
  for (int i = 0; i < RELAY_COUNT; i++) {
    digitalWrite(RELAY_PINS[i], HIGH);
  }
}

void actuatorOff(uint8_t index) {
  digitalWrite(ACTUATOR_PINS[index].east, HIGH);
  digitalWrite(ACTUATOR_PINS[index].west, HIGH);
}

// =====================================================================
// ADC helpers
// =====================================================================

void initAdc() {
  analogReadResolution(12);  // 0..4095
  for (int i = 0; i < ACTUATOR_COUNT; i++) {
    pinMode(POT_PINS[i], INPUT);
    analogSetPinAttenuation(POT_PINS[i], ADC_11db);  // ~0..3.3V
  }
}

int readAdcAvg(int pin, int samples) {
  long acc = 0;
  for (int i = 0; i < samples; i++) {
    acc += analogRead(pin);
    // Spread samples across a full 50 Hz mains cycle (~20 ms for 16 samples)
    // so hum/PWM aliasing averages out instead of clustering.
    if (i + 1 < samples) delayMicroseconds(ADC_INTERSAMPLE_US);
  }
  return static_cast<int>(acc / samples);
}

int readAdcStable(int pin) {
  // Take ADC_STABLE_SAMPLES independent averages, return the median. One
  // spike (e.g. a relay flick) lands in a single sample and gets discarded.
  int buf[ADC_STABLE_SAMPLES];
  for (int i = 0; i < ADC_STABLE_SAMPLES; i++) {
    buf[i] = readAdcAvg(pin);
  }
  // Insertion sort — tiny N, branch-predictable.
  for (int i = 1; i < ADC_STABLE_SAMPLES; i++) {
    int v = buf[i], j = i - 1;
    while (j >= 0 && buf[j] > v) { buf[j + 1] = buf[j]; j--; }
    buf[j + 1] = v;
  }
  return buf[ADC_STABLE_SAMPLES / 2];
}

float adcToVolts(int raw) {
  return raw * (3.3f / 4095.0f);
}

// =====================================================================
// Encoder
// =====================================================================

void Encoder::init() {
  pinMode(ENC_A,   INPUT_PULLUP);
  pinMode(ENC_B,   INPUT_PULLUP);
  pinMode(ENC_BTN, INPUT_PULLUP);
  prev_ab_ = readAB();
}

uint8_t Encoder::readAB() {
  uint8_t a = digitalRead(ENC_A);
  uint8_t b = digitalRead(ENC_B);
  return (a << 1) | b;
}

int8_t Encoder::decodeStep(uint8_t nibble) {
  // Quadrature gray-code lookup.
  // nibble = (prev_AB << 2) | curr_AB
  switch (nibble) {
    case 0b0001: case 0b0111: case 0b1110: case 0b1000: return +1;
    case 0b0010: case 0b1011: case 0b1101: case 0b0100: return -1;
    default: return 0;
  }
}

void Encoder::poll() {
  // Poll at most once per millisecond to avoid noise.
  uint32_t now = millis();
  if (now - last_poll_ms_ < 1) return;
  last_poll_ms_ = now;

  // Rotation
  uint8_t curr = readAB();
  uint8_t nibble = ((prev_ab_ & 0x03) << 2) | (curr & 0x03);
  steps_ += decodeStep(nibble);
  prev_ab_ = curr;

  // Button (edge detection: idle HIGH, pressed LOW)
  bool pressed = (digitalRead(ENC_BTN) == LOW);
  if (pressed && !button_last_) {
    button_pressed_ = true;
  }
  button_last_ = pressed;
}

int Encoder::consumeSteps() {
  int s = steps_;
  steps_ = 0;
  return s;
}

bool Encoder::consumeButtonPress() {
  bool p = button_pressed_;
  button_pressed_ = false;
  return p;
}

// =====================================================================
// RTC (DS3231 via I2C)
// =====================================================================

namespace RTC {

static constexpr uint8_t ADDR = 0x68;

static uint8_t dec2bcd(uint8_t v) { return ((v / 10) << 4) | (v % 10); }
static uint8_t bcd2dec(uint8_t v) { return (v >> 4) * 10 + (v & 0x0F); }

bool isPresent() {
  Wire.beginTransmission(ADDR);
  return Wire.endTransmission() == 0;
}
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

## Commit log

2026-03-29 Initial commit: ESP32 solar tracker project
    - Modular Arduino C++ firmware (SolarTracker/): config, hardware, FSM, UI
    - Original single-file firmware kept as .bak reference
    - Comprehensive documentation (docs/): hardware specs, wiring, power architecture, firmware, UI
    - 3D print files for enclosures
    - Rust ESP32 project skeleton (solar-tracker/): future port
    [Capac48to5V.3mf, Capac48to5V.stl, CapacSolarTracker.stl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]
2026-04-14 Add clock-set and monthly-config menus; semantic east/west pins
    - Rename ActuatorPins dir1/dir2 to east/west; swap array C to compensate
    for its inverted physical wiring (expressed once, in the pin table).
    - Add POT_CAL[] with end-stop ADC readings measured on 2026-04-13.
    - New SetClock page: view current RTC time; button enters edit mode
    (Year -> Month -> Day -> Hour -> Minute -> Second) with encoder
    adjustment, day clamped by days-in-month (leap-year aware), final
    press commits to DS3231.
    - Gate RTC-from-compile-time seed: only runs when year < 2024 or read
    fails, so menu-set values survive reboots.
    - New Config page: per-month tracking window (Start/End time + pot
    setpoint) st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
    [SolarTracker.ino, config.h, hardware.cpp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]
2026-04-15 Phase 2: closed-loop auto-tracking + ADC noise reduction
    AutoTrack controller
    - New autotrack.{h,cpp}: state machine (Off/Outside/Idle/Active) that
    drives each array toward an interpolated target pot reading based
    on the per-month config and RTC time. Walks A -> B -> C sequentially
    (respects the single-active-actuator buck invariant). Reuses MoveFSM
    unmodified.
    - Deadband 20 raw counts; chains up to 3 FSM pulses per actuator per
    pass for full-stroke catch-up; stall detection aborts an actuator
    if the pot hasn't moved >= 10 counts within 5 s.
    - Gates: user_busy, auto_enabled, RTC year >= 2024, month in range,
    per-month config valid, current time inside the [start, end] window.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
    [SolarTracker.ino, autotrack.cpp, config.h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]
2026-04-15 RTC: handle 12-hour mode, force 24-hour on write, validate on read
    Observed on hardware: DS3231 displaying hour=39 and subsequently
    arbitrary fluctuating values (45:85:85, 38:78:78, ticking into
    invalid-BCD territory). Likely root cause is power-supply glitches
    when actuator relays engage, corrupting the hours register and the
    DS3231 BCD rollover misbehaving under marginal Vcc. A genuine power
    fix belongs in hardware (decoupling caps at DS3231 Vcc, coin cell
    check, I2C routing) but the firmware should also detect and recover.
    Three defensive layers in hardware.cpp:
    1. RTC::read() now handles 12-hour mode explicitly. Previously
    "hour & 0x3F" kept bit 5, which is AM/PM in 12-hour mode, no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
    [hardware.cpp]
2026-04-15 setup(): harden cold boot against marginal 5V rail
    Observed on hardware: cold boot sometimes produces a blank LCD; the
    ESP32 is running (encoder input triggers garbage on the display) but
    lcd.begin() silently failed. Connecting USB in parallel recovers
    because the laptop provides a stiff 5V; disconnecting kills it again.
    The user's 5V rail comes from an XL7035-based wide-input buck module
    rated 1A max at 150kHz switching. Slow soft-start and poor transient
    response means the rail is not clean during the first ~1s after power
    is applied, and big simultaneous load steps (LCD backlight + relay
    coils + ESP32 boot) can briefly exceed the 1A limit and foldback.
    Four changes in setup(), none func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
    [SolarTracker.ino]
2026-04-15 I2C: explicitly set bus clock to 100 kHz
    Hardware observation: occasional character corruption on the LCD
    (missing leading letters, substitutions like P -> -) on a ~20 cm
    shared I2C bus with three devices (LCD backpack, DS3231, INA226)
    relying only on the modules' built-in weak pull-ups.
    Default Wire clock varies by ESP32 core version. At 400 kHz the
    rising edges on this bus are marginal because of wire capacitance
    plus weak pull-ups plus EMI pickup from the nearby actuator wires.
    Pinning to 100 kHz quadruples the time each edge has to settle,
    which turns "mostly works with occasional glitches" into "reliable"
    on most marginal bus layouts.
    This is a firmware mitigation; the real fix is har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
    [SolarTracker.ino]
